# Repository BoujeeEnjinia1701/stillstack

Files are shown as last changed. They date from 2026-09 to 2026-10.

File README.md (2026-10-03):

# StillStack

     

**Area:** Water Security · **TRL:** 3 of 9 (proof of concept on paper) · **Value-engineering target:** USD 355 (estimated cost of the constructable design about USD 443) · **Difficulty:** 3 of 5

Multi-stage wick still that reuses the latent heat of condensation from each stage in the next one.

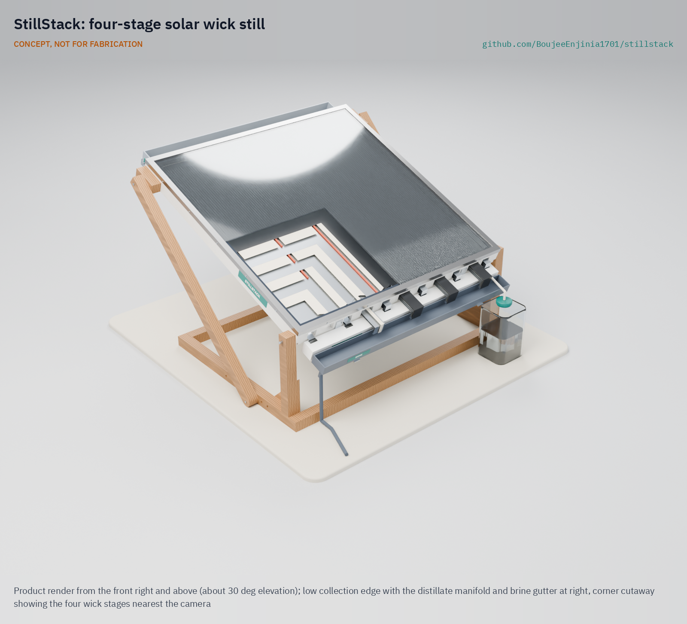
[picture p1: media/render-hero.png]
StillStack: four-stage solar wick still, product render


[Exploded render](media/render-exploded.png) · [Detail render](media/render-detail.png) · [Interactive 3D model](media/viewer.html) · [Concept blueprint (PDF)](media/concept-blueprint.pdf) · [General arrangement (PDF)](cad/drawings/SSK-DWG-002.pdf) · [Prototype build plan](docs/05-build-plan.md) · [Design decisions](docs/06-design-decisions.md) · [Sizing note](docs/04-calcs/01-sizing.md) · [Review note](docs/REVIEW.md)

## Concept rationale

A basin still wastes the heat it collects: vapor condenses on the glass and its latent heat goes to the sky. Stacking thin wick stages under metal plates lets each stage condense against the next one, so one day of sun evaporates water about four times over. The approach needs no pumps, electronics or membranes, which keeps it passive and repairable, and the calculated output of about 10.6 L per m2 per day is two to three times a basin still of the same area.

The design is open and garage-buildable because the people who need it most are rarely served by commercial desalination. Sheet aluminum, twin-wall polycarbonate, timber and cloth can be bought or salvaged almost anywhere, and a documented design lets an NGO, school or workshop build, test and adapt it rather than wait for a product.

## Burning platform

In 2024, 2.1 billion people, one in four worldwide, still lacked safely managed drinking water, and 106 million drank untreated surface water ([WHO and UNICEF, 2025](https://www.who.int/news/item/26-08-2025-1-in-4-people-globally-still-lack-access-to-safe-drinking-water---who--unicef)). The WHO estimates that in 2022 at least 1.7 billion people used a drinking water source contaminated with faeces, and that in 2021 over 2 billion people lived in water-stressed countries, a pressure that climate change and population growth are expected to worsen ([WHO drinking-water fact sheet](https://www.who.int/news-room/fact-sheets/detail/drinking-water)).

Many of these households sit beside seawater or above brackish aquifers that they cannot drink. Rising dry-season river salinity is projected across the southwest coast of Bangladesh by 2050 ([World Bank, 2015](https://www.worldbank.org/en/news/feature/2015/02/17/salinity-intrusion-in-changing-climate-scenario-will-hit-coastal-bangladesh-hard)). A still that turns salt water into distillate with sunlight alone, at several times the output of a basin still, addresses both problems at household scale.

## Where it could be used

### By industry

| Industry | Use |
| --- | --- |
| Humanitarian and WASH programs | Household or clinic distillate where only saline or brackish water is available |
| Island and remote tourism | Backup drinking and cooking water for eco-lodges and dive camps without reliable reverse osmosis |
| Off-grid energy | Distilled water for topping up lead-acid batteries in solar home and telecom systems |
| Education and technical training | A hands-on build for courses in heat transfer, water treatment and renewable energy |
| Field research stations | Low-salt water for rinsing instruments and small laboratory needs |

### By country or region

| Country or region | Why it matters there |
| --- | --- |
| Bangladesh (southwest coast) | Dry-season river salinity is projected to rise significantly by 2050, and eight coastal districts are the most affected ([World Bank](https://www.worldbank.org/en/news/feature/2015/02/17/salinity-intrusion-in-changing-climate-scenario-will-hit-coastal-bangladesh-hard)) |
| Kiribati (South Tarawa) | Groundwater from the freshwater lens can support only about half of South Tarawa's population, and households receive piped water for about 1.5 hours every two days ([World Bank](https://blogs.worldbank.org/en/eastasiapacific/drilling-for-water-in-kiribati)) |
| United States (Texas) | Texas aquifers hold about 2.7 billion acre-feet (about 3.3 x 10^12 m3) of brackish groundwater at 1,000 to 10,000 mg/L dissolved solids ([Texas Water Development Board](https://www.twdb.texas.gov/publications/reports/numbered_reports/doc/r363/b2.pdf)); small ranches and colonias could use it at household scale |
| Chile (Antofagasta region, Atacama coast) | The region holds the Atacama, the driest desert in the world, with about 1.7 mm of rain a year in Antofagasta; demand exceeds supply, and about 42 % of the rural population has no formal drinking-water supply ([Ruffino et al., IJERPH, 2022](https://doi.org/10.3390/ijerph192114406)) |
| Middle East and North Africa | The region has the world's lowest water availability per person, about 480 m3 a year in 2023, less than 10 % of the global average ([World Bank](https://blogs.worldbank.org/en/voices/in-mena-make-every-drop-of-water-count)); sun and seawater are plentiful |

## What sparked the idea

The starting point was a floating prototype that researchers at Politecnico di Torino tested in the Ligurian Sea at Varazze, Italy: a stack of thin evaporating and condensing layers fed by porous materials, with no pumps, which produced almost 3 L of distillate per m2 per hour from seawater at less than one sun ([Chiavazzo et al., Nature Sustainability, 2018](https://doi.org/10.1038/s41893-018-0186-x)); the university reported daily productivity of up to 20 L of drinking water per m2 ([Politecnico di Torino release via ScienceDaily](https://www.sciencedaily.com/releases/2019/01/190107131242.htm)). Their shift of attention from absorbing more sunlight to reusing the heat already absorbed is the principle behind StillStack. The gap it points at is that the result was a research device, not a design a community workshop could build; StillStack sets out to be that open, land-based, garage-buildable version.

## Problem

Single-basin solar stills make only about 3 to 5 L per m2 per day.

## Concept

Multi-stage wick still that reuses the latent heat of condensation from each stage in the next one.

The TRL 3 sizing (SSK-CAL-001) gives about 10.6 L per m2 per day on a 5.5 kWh per m2 day, with a gained output ratio of about 1.3. Dry stagnation reaches about 140 °C, so stages 1 and 2 use materials rated to 150 °C and a stagnation cover is supplied; the stage 3 margin is thin. Value-engineering target: USD 355. Estimated cost of the constructable design: USD 443.20 (USD 88.20 over the target).

Full design precis: [docs/02-concept.md](docs/02-concept.md)

## Key components

- Twin-wall polycarbonate glazing
- Insulated plywood frame with a stone wool liner
- Black aluminum absorber and four coated aluminum condenser plates
- Wick strips, four stages
- Side rails (150 °C polymer in stages 1 and 2, polycarbonate below) and silicone-cord spacer ribs
- Feed trough, lidded distillate manifold and brine gutter
- Rear heat-rejection fins and an adjustable tilt stand
- Opaque stagnation cover for when the feed runs out

The working bill of materials is in [bom/bom.csv](bom/bom.csv).

## Building the prototype

The [prototype build plan](docs/05-build-plan.md) (SSK-BLD-001) shows how to make each of the 20 components and put them together in 22 illustrated steps. The frame is a plywood box on a plywood base ring, lined with stone wool and closed by twin-wall glazing under an aluminium trim. The five aluminium plates are cut with a zigzag low edge so distillate leaves on tongues at the rib lines and brine on separate tongues over the closed manifold lid. The stand pivots on two front posts and is held by props pinned at one of six holes from 10° to 35°. The changes that made the concept buildable are in [SSK-DDR-003](docs/decisions/0003-design-for-construction.md), and decisions still open are in the [design decisions register](docs/06-design-decisions.md).

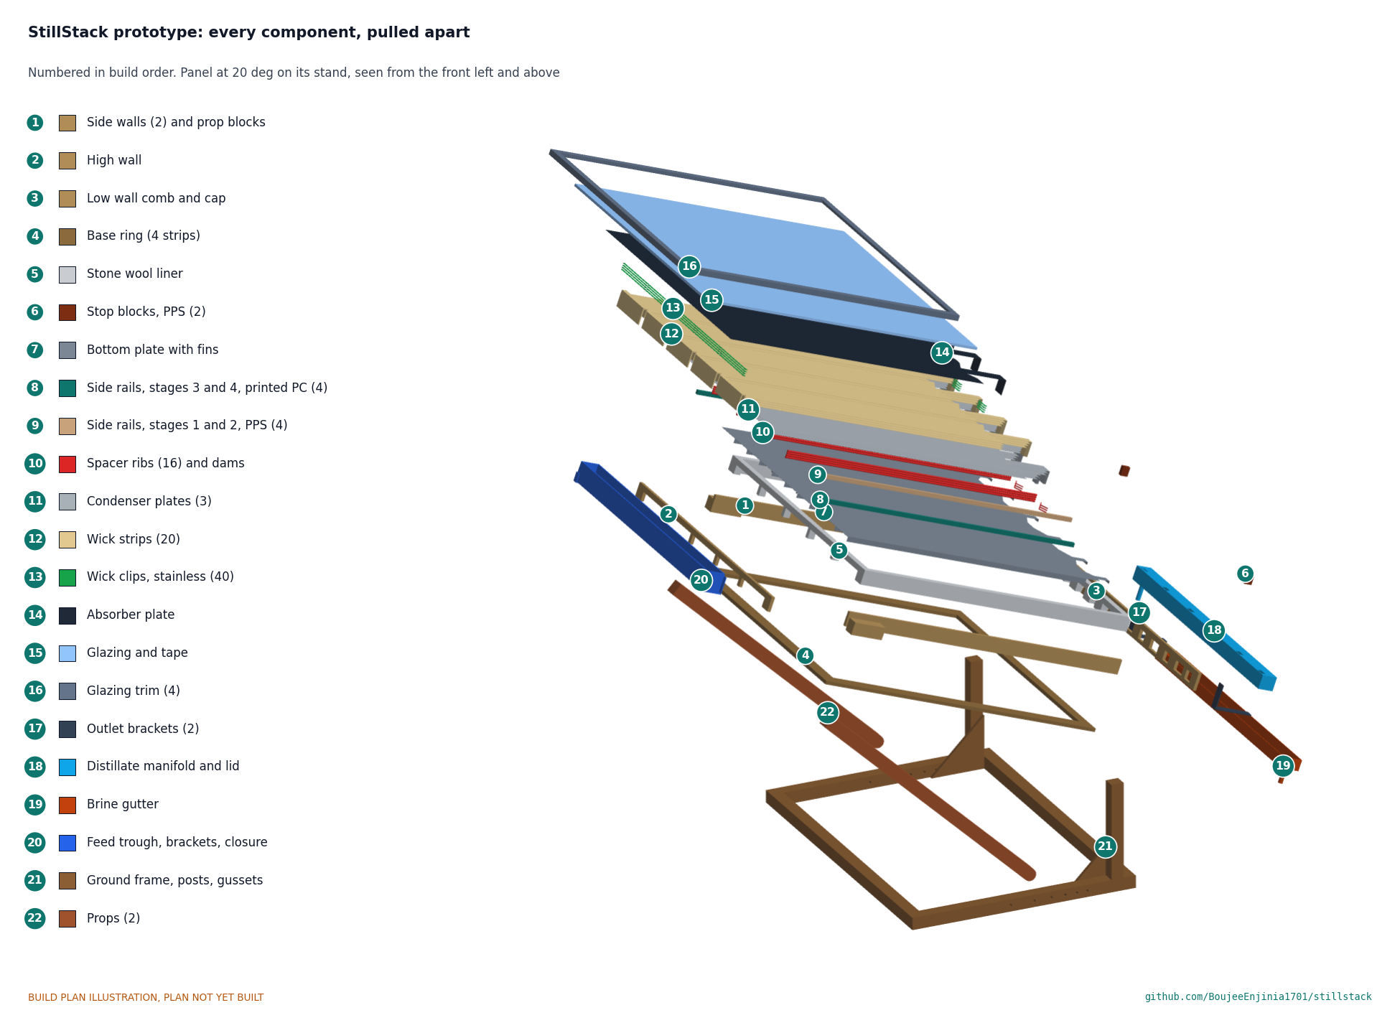
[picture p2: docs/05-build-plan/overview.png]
Every component of the StillStack prototype, pulled apart and numbered in build order


## Safety

> Distillate must be tested before drinking. Use food-safe materials on all wetted surfaces. The absorber reaches about 140 °C if the wicks run dry: fit the stagnation cover before maintenance and whenever the feed runs out. Anchor the stand against wind.

## Repository layout

| Folder | Contents |
| --- | --- |
| `docs/` | Problem, concept, requirements, calculations and design decisions |
| `cad/src/` | build123d Python source, the source of truth for all geometry |
| `cad/step/`, `cad/stl/` | Exported models for FreeCAD, other CAD tools and printing |
| `cad/drawings/` | 2D sketches and dimensioned drawings |
| `bom/` | Bill of materials |
| `electronics/` | KiCad schematics and PCB layouts |
| `firmware/` | Microcontroller code |
| `media/` | Renders, perspectives and photos |
| `build-log/` | Dated prototyping notes |

## Documentation

Controlled documents follow the portfolio [documentation standard](.kit/STANDARDS.md). Each carries a document ID (SSK-PRC-001 for the precis), a version and a revision history. Branded PDFs are built with `python .kit/render.py` and attached to GitHub Releases when a document is tagged, for example `SSK-PRC-001/v1.0`.

## Credits

Designed by Amish Chadha. See [CONTRIBUTORS.md](CONTRIBUTORS.md) for roles. To cite this design, use [CITATION.cff](CITATION.cff) (GitHub shows it as "Cite this repository").

AI assistance (Claude) was used to accelerate concept renders, prototype documentation and first-pass sizing calculations. Design direction and all decisions are Amish Chadha's, recorded in this repository's decision records (`docs/decisions/`).

## Licenses

- **Hardware** (CAD, drawings, BOM, electronics): [CERN-OHL-S v2](LICENSE)
- **Software** (firmware, scripts, notebooks): [MIT](LICENSE-SOFTWARE)

A project of the [Design Molecule](https://designmolecule.com) lab.

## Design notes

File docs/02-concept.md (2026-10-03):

---
doc_id: SSK-PRC-001
title: StillStack design precis
project: StillStack
doc_type: Design precis
version: "0.8"
status: Draft
date: '2026-10-02'
author: Amish Chadha
license: CERN-OHL-S-2.0
revisions:
- version: "0.1"
  date: '2026-09-24'
  author: Amish Chadha
  change: Initial scaffold
- version: "0.2"
  date: '2026-09-24'
  author: Amish Chadha
  change: Populate to TRL 2 (architecture, first-order numbers, design choices, safety, media)
- version: "0.3"
  date: '2026-09-25'
  author: Amish Chadha
  change: TRL 3 update; decided design choices (SSK-DDR-001), spacer ribs, numbers from SSK-CAL-001, parametric model and GA drawing
- version: "0.4"
  date: '2026-09-25'
  author: Amish Chadha
  change: Recommendations accepted by Amish (DDR-002)
- version: "0.5"
  date: '2026-09-26'
  author: Amish Chadha
  change: Budget top-up approved by Amish
- version: "0.6"
  date: '2026-10-01'
  author: Amish Chadha
  change: Constructable design (SSK-DDR-003, open for Amish's review); budget as a value-engineering target
- version: "0.7"
  date: '2026-10-02'
  author: Amish Chadha
  change: "Decisions of 2026-10-02: coating rule, wick fabric test and clips, PPS rails, high-edge lip, conductivity pass condition, partner, labels and rail colours"
- version: "0.8"
  date: '2026-10-02'
  author: Amish Chadha
  change: "Approved follow-ups carried into the design: mass 18.7 kg, cost USD 443.20, lip tabs and wick clips in the model"
---

# StillStack design precis

StillStack is a tilted, glazed panel of 1 m2 containing four thin evaporation stages stacked like a sandwich: each stage is a wet cloth wick under a metal plate, a 6 mm vapor gap, and the next plate below. Sunlight heats the top plate, and the heat released when vapor condenses on each plate evaporates water from the wick under it, so the same solar energy is used four times. The TRL 3 calculation (SSK-CAL-001) gives about 10.6 L of distillate per m2 per day on a 5.5 kWh per m2 day, roughly two to three times a single-basin still, with a gained output ratio of about 1.3. Dry stagnation reaches about 140 °C (144 °C in calm air), so stages 1 and 2 use materials rated to 150 °C and a stagnation cover is supplied (SSK-DDR-002). Value-engineering target: USD 355. Estimated cost of the constructable design: USD 416.20 (USD 61.20 over the target). How each part is made and fitted is in the prototype build plan (SSK-BLD-001); the changes that made the concept buildable are in SSK-DDR-003, open for Amish's review.

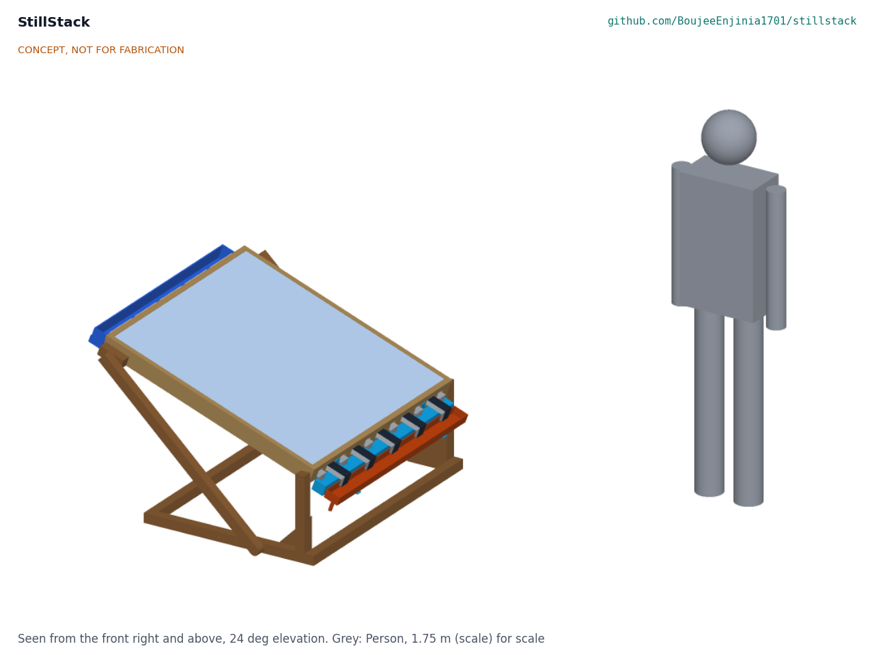
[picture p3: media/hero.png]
Hero render


## How it works

1. **Collect.** Sunlight passes through twin-wall polycarbonate glazing (solar transmittance about 0.80) and is absorbed by a black-coated aluminum plate. A 25 mm air gap under the glazing limits heat loss from the top.
2. **Evaporate, stage 1.** Cloth wick strips bonded to the underside of the absorber are kept wet with feed water. Heat conducts through the plate and evaporates water from the wick.
3. **Condense and reuse.** The vapor crosses a 6 mm gap and condenses on the top face of the next plate. The latent heat released there (about 2.35 MJ per kg at stage temperatures) conducts through that plate into the wick under it, which evaporates water into stage 2. The cascade repeats through four stages, each running about 3.7 K cooler than the one above at noon. Between 85 and 91 % of the heat crossing each gap at noon is latent.
4. **Hold the gaps.** Each gap has two side rails (a polymer rated to 150 °C in stages 1 and 2, printed polycarbonate in stages 3 and 4) and four silicone-cord ribs running down the slope at 194 mm pitch, so the 0.5 mm plates sag no more than about 0.5 mm. The wicks are cut into five strips with 10 mm dry breaks at every rib and rail.
5. **Reject heat.** The bottom plate is the last condenser. Folded aluminum fins on its shaded underside reject the remaining heat (6.6 MJ per day, peak 277 W/m2) to air at about 28 K above ambient.
6. **Feed and drain.** Feed water drips from a user-filled container into a trough along the high edge. The wick tails pass out through openings in the high wall, rise behind a foam closure and drop into the trough, and the wicks are fed by capillary action and gravity down the slope. Excess salty water leaves the low end of each wick into a brine gutter that sits outboard of, and lower than, the distillate manifold.
7. **Collect distillate.** Condensate runs down each condenser plate to its zigzag low edge, which leads it to six tongues at the rib lines and corners. The tongues pass through notches in the low wall and turn down through slots in a lidded distillate manifold, which drains through a spout into a clean covered container. Brine leaves on separate tongues at the strip centres, carrying the wick tails over the closed lid into the brine gutter (SSK-DDR-003, proposed, awaiting Amish).

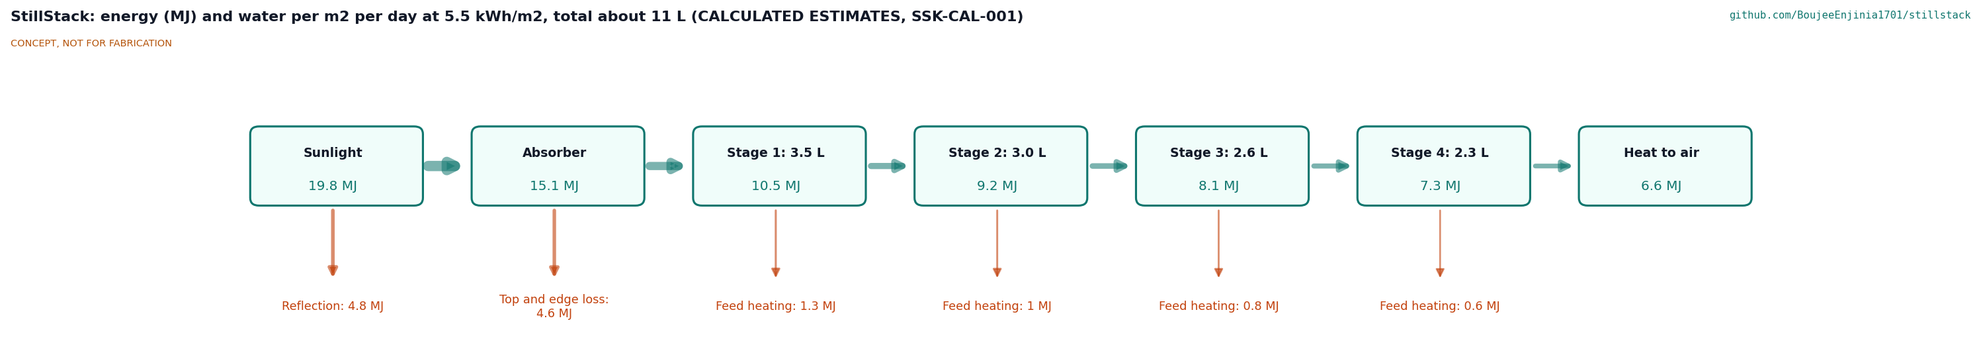
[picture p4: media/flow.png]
Energy and water flow (calculated estimates)


## Main components

Table 1. Main components, numbered to match the exploded view and bom/bom.csv.

| # | Component | Choice | Notes |
| --- | --- | --- | --- |
| 1 | Glazing | 6 mm twin-wall UV-stabilized polycarbonate, 1.0 x 1.0 m | Inner sheet reaches about 109 °C at dry stagnation |
| 2 | Insulated frame | 12 mm exterior plywood walls on a plywood base ring, with 25 mm foil-faced stone wool liner, 1,074 mm square outside; glazing held by an aluminium trim | Stone wool replaces PIR (SSK-DDR-002) because the absorber edge reaches about 144 °C at dry stagnation |
| 3 | Absorber plate | 0.5 mm aluminum, high-temperature matte black paint on top | Stage 1 evaporator surface underneath |
| 4 | Wicks, 4 stages | Viscose-polyester or cotton nonwoven, about 1 mm, 1.0 x 1.25 m, cut into five strips | Needs a permeability of 3.0 x 10^-11 m2 or more and must tolerate 150 °C dry; product not yet selected |
| 5 | Condenser plates, 4 | 0.5 mm aluminum with a food-contact coating on the condensing face; 77 mm lip into the manifold | Coating rated to 150 °C on plates 1 and 2 and certified for drinking-water contact; the lowest-cost such coating (fluoropolymer cookware coatings first), else 316 stainless plates 1 and 2 (decided 2026-10-02); 4 mm downturned lip on each condensing plate's high edge (decided 2026-10-02) |
| 6 | Side spacer rails | 12 x 7 mm, two per gap: stages 1 and 2 in PPS, rated to 150 °C or more (decided 2026-10-02); stages 3 and 4 in printed polycarbonate | Split by SSK-DDR-002; ASA excluded by the stagnation temperature |
| 7 | Spacer ribs | 7 mm food-grade silicone cord, four per gap at 194 mm pitch | Decided (SSK-DDR-002) |
| 8 | Feed trough | PVC or HDPE rain gutter section with end caps and drip valve | Fed from a user-filled container |
| 9 | Distillate manifold | Food-grade PP or HDPE channel with lid and silicone outlet tube | Separate outlet from the brine |
| 10 | Brine gutter | PVC gutter outboard of and below the distillate manifold, with drain hose | Brine to a soak-away or evaporation pond |
| 11 | Rear heat-rejection fins | Ten folded 0.5 mm aluminum strips, 30 mm deep | On the shaded underside of the bottom plate |
| 12 | Adjustable tilt stand | 45 x 45 mm timber ground frame, front posts with a pivot bolt, fixed props pinned at one of six holes | 10 to 35 deg in 5 deg steps (R11) |
| 13 | Sealant, fasteners and tubing | NSF/ANSI 51 or 61 silicone, stainless screws, silicone tube | Not shown in the model |
| 14 | Stagnation cover | Opaque white or aluminized tarpaulin 1.3 x 1.3 m with elastic edge cord | Fitted when the feed runs out and before maintenance; not shown in the model |

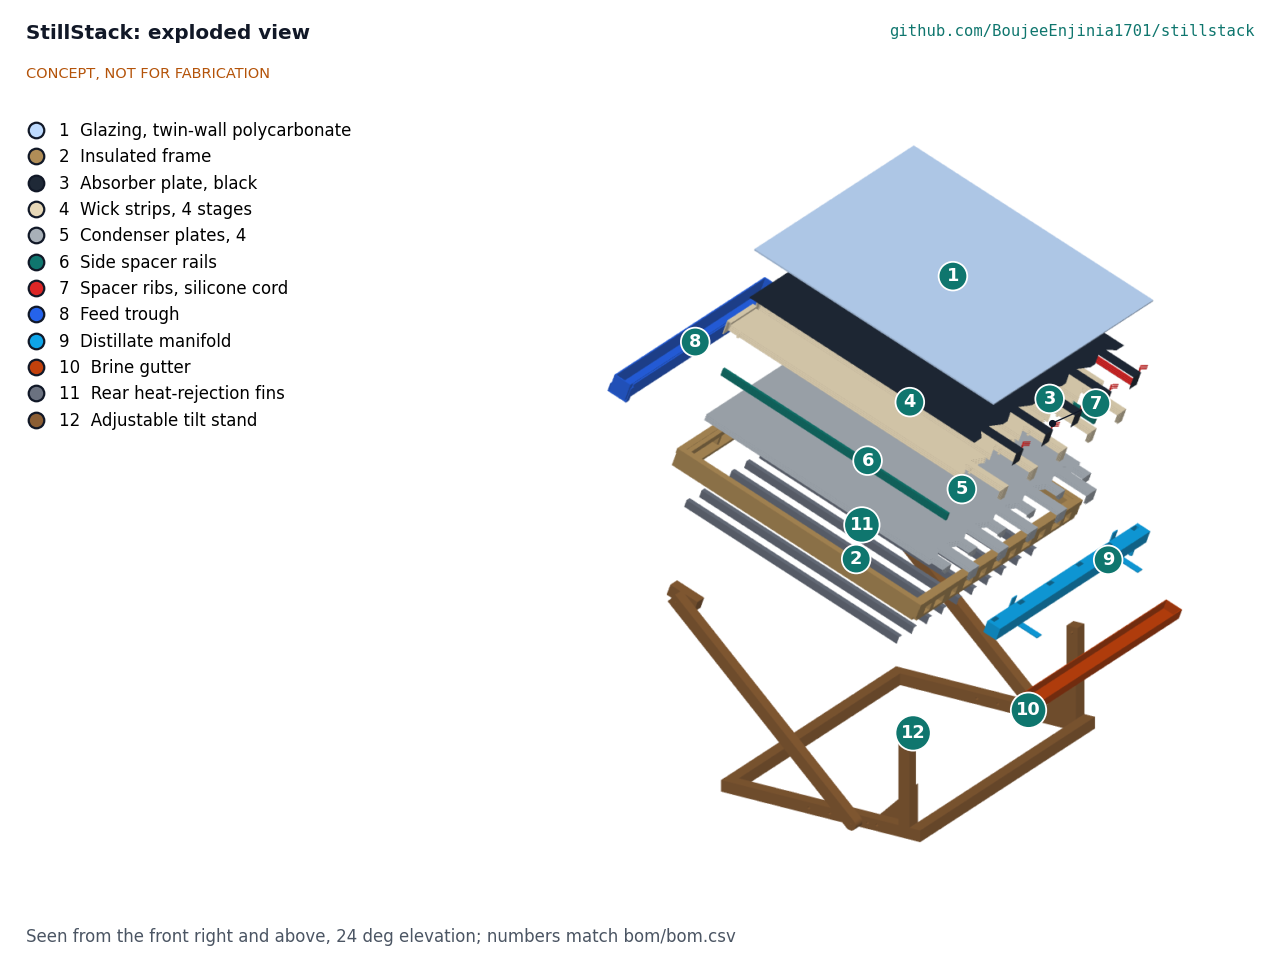
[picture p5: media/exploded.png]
Exploded view


## Key numbers

All values come from SSK-CAL-001 (quasi-steady stack model integrated over a 5.5 kWh per m2 design day) and are calculated estimates, not measurements.

Table 2. Key numbers per m2 of aperture.

| Quantity | Value | Requirement |
| --- | --- | --- |
| Solar input | 19.8 MJ per day | |
| Optical loss | 4.8 MJ (τα = 0.76) | |
| Top loss | 4.5 MJ | |
| Feed heating lost with brine | 3.8 MJ | |
| Heat rejected at the bottom | 6.6 MJ, peak 277 W/m2 | |
| Distillate by stage | 3.45, 2.97, 2.60, 2.29 L | |
| Daily distillate | 10.6 L after warm-up deduction (11.3 L quasi-steady); range 9.0 to 13.6 L for 4.5 to 6.5 kWh per m2 | R1 met, 6 % margin |
| Gained output ratio | 1.26 to 1.34 | R2 at risk |
| Plate temperatures at noon | 73, 69, 66, 62 and 58 °C | |
| Dry stagnation, stage 1 | about 140 °C (144 °C calm); stage 3 about 110 °C calm | R8 at risk (150 °C and 110 °C ratings) |
| Feed and brine | about 28.7 L feed, 17.2 L brine per day; brine 58 to 67 g/L | R6 at risk (wick feed) |
| Panel mass | 18.7 kg dry, 22.7 kg wet; stand 8.9 kg | R9 met |
| Parts cost | USD 443.20 against a USD 355 value-engineering target | R12 USD 88.20 over the target |

## Key design choices

These choices were decided by Amish on 2026-09-25 (SSK-DDR-001 and SSK-DDR-002).

- **Four stages with 6 mm gaps.** Decided. Three stages would give about 9.1 L per day; six stages about 14.9 L on paper.
- **Air-cooled fins under the bottom plate.** Decided. The bottom plate stays near 58 °C at noon, which is adequate for four stages.
- **Aluminum plates with a food-contact coating on the condensing face.** Decided. The coating product is not yet selected; see open questions.
- **Spacers in ASA or polycarbonate, not PETG.** Decided. SSK-CAL-001 shows that only polycarbonate is close to adequate, because stages 1 to 3 exceed the rating of ASA at dry stagnation.
- **Tilt of 20 deg on an adjustable stand.** Decided. The stand pivots at the low edge and sets the tilt with rear struts from 10 to 35 deg.
- **Aperture of 1 m2 and a value-engineering target of USD 355.** Decided. The budget was kept at $250 in SSK-DDR-001, raised to $320 in SSK-DDR-002 and topped up to $355 by Amish on 2026-09-26; on 2026-10-01 Amish set it as a value-engineering target, not a limit. The constructable design is estimated at USD 416.20.
- **Intermediate silicone-cord ribs.** Decided (SSK-DDR-002). The calculation shows that side rails alone cannot hold a 6 mm gap; silicone is rated well above the stagnation temperature and wets poorly.
- **Dry stagnation handled by materials and a cover.** Decided (SSK-DDR-002). Everything in stages 1 and 2 is rated to 150 °C or more, the frame liner is stone wool, and an opaque stagnation cover is supplied with a shade rule.

## Safety

> **Safety:** Distillate is not certified drinking water. Test it before drinking (at least conductivity and E. coli), store it in a clean covered container, and disinfect it (for example with chlorine) before use. Each stage's distillate conductivity test is a pass condition at TRL 4 before any water is drunk (decided 2026-10-02). Stages run below pasteurization certainty, brine can wick or splash into distillate channels, and volatile contaminants in the feed can carry over with the vapor. Long-term drinking of distillate needs remineralization.

> **Safety:** Use only food-contact rated materials on every surface that touches distillate: coated or stainless plates, PP or HDPE channels, and NSF/ANSI 51 or 61 silicone. Never use lead-containing solder, treated timber or recycled containers of unknown history in the water path.

> **Safety:** The absorber reaches about 80 °C in normal use and about 140 °C when the wicks run dry. Do not touch the glazing or open the stack in sun. Fit the stagnation cover (BOM line 14) before maintenance and whenever the feed container runs empty, and never leave a dry panel uncovered in sun.

> **Safety:** The panel and stand can overturn at about 17 m/s of wind. Anchor or ballast the stand.

- Brine is strongly saline. Discharge it away from crops, wells and soil that must stay fresh.

## Open questions

Decided by Amish on 2026-10-02 (SSK-DEC-001); the questions that remain are what the tests will show:

- Coating (R7): the lowest-cost coating certified for drinking-water contact (NSF/ANSI 61 or an equivalent food-contact statement) in hot salty water and rated to 150 °C dry; fluoropolymer (PTFE type) cookware coatings are checked first; if none meets both, 316 stainless for plates 1 and 2. Which product passes is still to be found.
- Wick fabric (R6): one polyester or polyester-viscose nonwoven and one glass-fibre fabric are shortlisted from datasheets and compared by a wicking-rise test; the cheaper one that reaches 3.0 x 10^-11 m2 and tolerates 150 °C dry is chosen. Wick fixing (R10): clips at the high and low ends, no adhesive.
- Rail polymer (R8): PPS for the stage 1 and 2 rails and stop blocks. Whether stage 3 can keep any margin over 110 °C in calm air is still open.
- Brine and feed separation (R4): the zigzag edge detail of SSK-DDR-003 (A1) and a 4 mm downturned lip on each condensing plate's high edge (A2); each stage's distillate conductivity at TRL 4 decides whether they work.
- Partner: a university water or desalination lab first; first candidate to approach, the Politecnico di Torino group behind the 2018 floating multistage still; a coastal NGO for field use once the distillate passes its tests. Nothing is agreed yet.
- Outlets and rails are marked DISTILLATE and BRINE, and the stage 1 and 2 rails have their own colour, so outlets are not mixed and a low-temperature rail is not fitted in a hot stage.

Design data: [general arrangement SSK-DWG-002](../cad/drawings/SSK-DWG-002.pdf), [sizing SSK-CAL-001](04-calcs/01-sizing.md), [parametric model](../cad/src/model.py), [blueprint sheet](../media/concept-blueprint.pdf), [interactive 3D model](../media/viewer.html), [cutaway](../media/cutaway.png).

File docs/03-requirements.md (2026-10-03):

---
doc_id: SSK-REQ-001
title: StillStack requirements
project: StillStack
doc_type: Requirements
version: "0.8"
status: Draft
date: '2026-10-02'
author: Amish Chadha
license: CERN-OHL-S-2.0
revisions:
- version: "0.1"
  date: '2026-09-24'
  author: Amish Chadha
  change: Initial scaffold
- version: "0.2"
  date: '2026-09-24'
  author: Amish Chadha
  change: First measurable requirements for TRL 2
- version: "0.3"
  date: '2026-09-25'
  author: Amish Chadha
  change: Add TRL 3 status from SSK-CAL-001; record decisions from SSK-DDR-001 (budget kept at $250, tilt stand, aperture); targets unchanged
- version: "0.4"
  date: '2026-09-25'
  author: Amish Chadha
  change: Recommendations accepted by Amish (DDR-002)
- version: "0.5"
  date: '2026-09-26'
  author: Amish Chadha
  change: Budget top-up approved by Amish
- version: "0.6"
  date: '2026-10-01'
  author: Amish Chadha
  change: Status from the constructable design (SSK-DDR-003); R12 reported against the value-engineering target
- version: "0.7"
  date: '2026-10-02'
  author: Amish Chadha
  change: "Decisions of 2026-10-02 noted under R4, R6, R7, R8 and R10 (lip, conductivity pass condition, fabric test, coating rule, PPS, wick clips); no status changed"
- version: "0.8"
  date: '2026-10-02'
  author: Amish Chadha
  change: "Approved follow-ups carried into the design: R9 mass 18.7 kg, R12 USD 443.20 (USD 88.20 over the target), R4 lip modelled, R10 moves from at risk to met on paper (wick clips modelled)"
---

# StillStack requirements

These requirements were checked by calculation at TRL 3 in SSK-CAL-001 v0.6. No requirement is **not met**; five are at risk and one cannot be verified until TRL 4. The TRL 2 review decisions (SSK-DDR-001) kept the 1 m2 aperture and the 20 deg tilt on an adjustable stand. Under SSK-DDR-002 (decided by Amish on 2026-09-25, going with the recommendations) R8 was restated with a 150 °C rating for stages 1 and 2 plus a stagnation cover, and the R12 budget was raised from $250 to $320. The added materials and cover bring the parts to $351.20. On 2026-09-26 Amish approved a budget top-up to $355 (SSK-DDR-002 v0.2). On 2026-10-01 Amish set every budget as a value-engineering target rather than a limit, so R12 is reported against it. The constructable design of SSK-DDR-003 (made under Amish's 2026-09-30 instruction to make the design buildable; open for his review) was estimated at USD 416.20. With the approved follow-ups of 2026-10-02 (PPS rails, wick clips, labels) it is estimated at USD 443.20, USD 88.20 over the USD 355 target. Carrying the wick clips into the model moves R10 from at risk to met on paper; no other status changes.

Table 1. Requirements and status at TRL 3.

| ID | Requirement | Target | Verification (TRL 3 or later) | Status at TRL 3 (SSK-CAL-001) |
| --- | --- | --- | --- | --- |
| R1 | Produce more distillate per unit area than a basin still | 10 L per m2 of aperture per day or more on a clear day with 5.5 kWh per m2 of sun (design goal 13 L) | Stage energy balance calculation; later outdoor test with a single-basin still alongside | Met on paper: 10.6 L after warm-up deduction (11.3 L quasi-steady); the 13 L goal is not met |
| R2 | Reuse the latent heat of condensation | Daily gained output ratio (latent heat in distillate divided by solar input) of 1.3 or more | Stage energy balance calculation | At risk: 1.34 quasi-steady, 1.26 after warm-up deduction |
| R3 | Remove salt | Distillate conductivity 75 µS/cm or less (about 50 mg/L dissolved solids) from feed up to 40 g/L salinity | Calculation of carryover paths; later conductivity meter | Not verifiable at TRL 3: brine carryover must stay below 0.075 % of the distillate (8.5 mL per day) |
| R4 | Keep brine and distillate apart | A physical air break of 10 mm or more between every wick edge and every distillate channel; no shared drain | Design review of the model | At risk: 10 mm dry breaks at ribs, rails and inside the plate edges; brine tongues carry the wick tails 10.5 mm or more above the closed manifold lid and at least 44 mm from any distillate tongue (SSK-DDR-003 A1, accepted 2026-10-02); feed tails cross the condensing plates' high edges 6 mm above them, to be guarded by a 4 mm downturned lip on each condensing plate's high edge (A2 (c), decided 2026-10-02, now in the model as four tabs on each plate). Each stage's distillate conductivity test at TRL 4 is a pass condition before any water is drunk |
| R5 | Run without power | No pumps, electronics or batteries; gravity feed from a user-filled container at most 1.5 m above ground | Design review | Met: fully passive; feed trough rim at most 1.00 m (at 35 deg) |
| R6 | Accept real feed water | Seawater or brackish water up to 40 g/L salinity after cloth or 20 µm prefiltering; feed-to-distillate ratio 2.5 or more so salt stays in solution | Salt balance calculation | At risk: brine at 66.7 g/L is well below saturation, but the wick needs a permeability of 3.0 x 10^-11 m2 or more to carry the feed, which is not yet known; the fabric is chosen by a wicking-rise test between a polyester-type nonwoven and a glass-fibre fabric (decided 2026-10-02) |
| R7 | Food-safe wetted parts | Every surface that touches distillate is food-contact rated (for example 316 stainless steel, food-grade coated aluminum, PP, HDPE or NSF/ANSI 51 or 61 silicone) | Material list review | At risk: coated aluminum is decided, the coating class is selected (fluoropolymer, PTFE or PFA type, BOM line 5) but no named product with a drinking-water certificate for wet, salty service at 80 °C (and 150 °C dry on plates 1 and 2) has been seen. Rule decided 2026-10-02: the lowest-cost coating certified for drinking-water contact and rated to 150 °C dry (fluoropolymer cookware coatings first), else 316 stainless for plates 1 and 2 |
| R8 | Survive dry stagnation | No damage after an empty-wick day at 1,000 W/m2 and 35 °C ambient, in calm air or wind: materials in stages 1 and 2 (absorber to plate 2, including wicks, rails, ribs, coating and liner) rated to 150 °C or more; all other internal materials rated to 110 °C or more; a stagnation cover supplied and a shade rule in the instructions (restated under SSK-DDR-002) | Stagnation temperature calculation; material datasheets | At risk: stages 1 and 2 reach 144 °C in calm air (6 K margin); stage 3 reaches 110 °C in calm air (0 K margin); cover specified (BOM line 14); rail polymer decided as PPS (2026-10-02, BOM line 6); coating class selected (fluoropolymer) but its drinking-water certificate not yet seen |
| R9 | Household scale and portable | 1.0 m2 aperture; panel mass 20 kg or less dry; carried by two people; footprint within 1.3 x 1.3 m | Massing model and mass estimate | Met: 18.7 kg dry (22.7 kg wet); footprint 1.28 x 1.25 m at 10 deg |
| R10 | Easy maintenance | Wicks removable, rinsed and refitted by one person without special tools in 30 min or less; salt flushing no more often than once a week | Design review | Met on paper: the plates lift out once the low wall cap is off, and each wick is held by two stainless clips, at its high end and on its brine tongue, with no adhesive (decided 2026-10-02; in the model, SSK-DWG-119 and 120), so the wicks lift out; the 30 minute time is to be shown at TRL 4 |
| R11 | Adjustable tilt | Tilt between 10 and 35 deg to suit latitudes of about 0 to 35 deg | Model check | Met: props pinned at six holes, 10 to 35 deg in 5 deg steps; model built and checked at each |
| R12 | Low cost and buildable | Parts cost against a value-engineering target of USD 355 for the 1 m2 prototype (budget_usd; a hypothetical control target, not a limit, Amish 2026-10-01); hand tools, sheet metal shears and a 3D printer only | Priced BOM | USD 88.20 over the value-engineering target: estimated USD 443.20 for the constructable design (SSK-DDR-003, with the PPS rails, wick clips and labels of 2026-10-02) |

## Assumptions

- Design day: 5.5 kWh per m2 per day (19.8 MJ per m2) on the tilted aperture, 30 °C mean daytime ambient, light wind (1 m/s in SSK-CAL-001).
- Latent heat of vaporization: SSK-CAL-001 uses temperature-dependent values (about 2.33 to 2.36 MJ per kg over the stage range) in place of the flat 2.26 MJ per kg used at TRL 2.
- The WHO does not set a health-based limit for dissolved solids; 50 mg/L is chosen as a check that salt carryover is negligible, not as a potability limit.
- Household need of about 3 L per person per day for drinking and 2 L for cooking, so 10 to 11 L per day serves a household of two.

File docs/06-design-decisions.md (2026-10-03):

---
doc_id: SSK-DEC-001
title: StillStack design decisions register
project: StillStack
doc_type: Design decisions register
version: "0.3"
status: Draft
date: '2026-10-02'
author: Amish Chadha
license: CERN-OHL-S-2.0
revisions:
  - version: "0.1"
    date: '2026-10-01'
    author: Amish Chadha
    change: Register opened with the design for construction (SSK-DDR-003); budget treated as a value-engineering target
  - version: "0.2"
    date: '2026-10-02'
    author: Amish Chadha
    change: "Amish approved the recommendations for open decisions 1 to 9 (2026-10-02); moved to decisions made (SSK-DDR-003 accepted, A2 as option (c))"
  - version: "0.3"
    date: '2026-10-02'
    author: Amish Chadha
    change: "Value engineering restated for the follow-ups carried into the design (USD 443.20, USD 88.20 over the target); two items to confirm when parts are bought"
---

# StillStack design decisions register

Every design decision still to be made, and every decision made, in one place. Each decision is argued in full in its decision record under `docs/decisions/`; this register is the index Amish works from. The build plan (`docs/05-build-plan.md`) describes the design as it stands and does not list open decisions.

## Open decisions

None. All open decisions were decided on 2026-10-02.

## To confirm when parts are bought

| # | What to confirm | Why it matters | Source |
| --- | --- | --- | --- |
| 1 | The manifold channel is about 56 x 50 mm with a snap-on lid that can be slotted | Sets the tongue bends and the lid slots (sketch SSK-DWG-114) | SSK-DDR-003 |
| 2 | The brine gutter is about 70 x 40 mm and the trough about 70 x 70 mm, with fascia brackets that fit it | Sets the outlet bracket length and the trough position | SSK-DDR-003 |
| 3 | The stone wool board has a compressive strength of 10 kPa or more | The glazing edge and its trim press on the liner tops | SSK-DDR-003 |
| 4 | The twin-wall sheet can be cut to 1,060 mm square with the flutes running down the slope, and breather tape is available for the flute ends | Drainage of condensate and rain from the flutes | SSK-PRC-001 |
| 5 | 7 mm PPS sheet (the stage 1 and 2 rail polymer, decided 2026-10-02) is sold in strips or small sheets | The rails and stop blocks are cut from it | SSK-DDR-002 |
| 6 | The coating and the high-temperature silicone adhesive bond to each other and to bare aluminium | The fins are bonded under the bottom plate; the chevron dams sit on the coating | SSK-DDR-003 |
| 7 | A quote for the 7 mm PPS sheet (BOM line 6 is priced at a distributor list price of about USD 70 per kg, not a quote) | The rails cost about USD 46 for four at that price | SSK-DEC-001 |
| 8 | The coater supplies an NSF/ANSI 61 or equivalent drinking-water certificate for the fluoropolymer coating in hot salty water, rated to 150 °C dry | Decides whether plates 1 and 2 keep the coating or move to 316 stainless | SSK-DEC-001 |

## Value engineering

Value-engineering target: USD 355 (a hypothetical control target, not a limit). Estimated cost of the constructable design: USD 443.20 (USD 88.20 over the target). Main cost drivers and savings worth trying:

- The largest lines are the five coated aluminium plates (USD 128 together, lines 3 and 5), the side rails (USD 60, line 6), the frame and liner (USD 35), the glazing (USD 32), the stand (USD 28) the glazing trim and tape (USD 20) and the 40 stainless wick clips (USD 14).
- The decisions of 2026-10-02 added USD 27: PPS rails at list price (USD 10), the wick clips (USD 14) and the labels (USD 3).
- Making the design constructable added USD 65: larger plate blanks for the tongues (USD 20), the glazing trim and tape (USD 20), the stand's ground frame, gussets and pins (USD 7), brackets for the trough and outlets (USD 10), the feed closure (USD 6) and longer wicks (USD 2).
- Savings worth trying: nest the plates' tongues when ordering cut sheet so the blank is nearer 1.0 x 1.1 m (about USD 10); fold the trim from aluminium flashing instead of buying angle (about USD 8); silicone strip in place of the 150 °C polymer rails in stages 1 and 2 (about USD 14, from SSK-DDR-002) is not a saving to take, because it would undo the R8 materials decision (SSK-DDR-002, item 2) and the PPS rails decided on 2026-10-02; move the brine gutter closer to the manifold to shorten the brine tongues; reclaimed timber for the stand; a locally made stagnation cover.

## Decisions made

| Date | Decision | Decided by | Record |
| --- | --- | --- | --- |
| 2026-09-25 | Four stages with 6 mm gaps; air-cooled fins; aluminium condenser plates with a food-contact coating; spacers in ASA or polycarbonate, not PETG; 20 deg tilt on an adjustable stand; 1 m2 aperture; budget kept at USD 250 | Amish: "proceed with all of your recommendations across all batches. Make sure we don't proceed to TRL 4 on any of them." | [SSK-DDR-001](decisions/0001-trl2-review-decisions.md) |
| 2026-09-25 | Silicone-cord ribs; R8 response (c): 150 °C materials in stages 1 and 2, stone wool liner, stagnation cover; budget raised to USD 320 | Amish: "i accept all your recommendations, go with them across all repos." | [SSK-DDR-002](decisions/0002-recommendations-accepted.md) |
| 2026-09-26 | Budget top-up to USD 355 | Amish: "I am ok with the budget top ups" | [SSK-DDR-002](decisions/0002-recommendations-accepted.md) v0.2 |
| 2026-09-30 | Make the design physically buildable while drawing the build plan | Amish: "If you are realising that the design cannot be built as per concept - fix the design assumptions to match and be physically feasible as you draw the illustrations." | [SSK-DDR-003](decisions/0003-design-for-construction.md) (changes accepted on 2026-10-02, below) |
| 2026-09-30 | Open decisions live in this register, not in the build plan | Amish: "don't log outstanding decisions in this build plan - that is not the place for it." | This register |
| 2026-10-01 | `budget_usd` is a value-engineering target, not a limit | Amish: "the budgets are a hypothethical control target to ensure we are thinking along a value engineering lens" | This register, Value engineering |
| 2026-10-02 | Design for construction accepted: the changes P1 to P12 and their knock-on changes, as made, with the two brine-separation details decided separately (A1 and A2, below) and the wick fixing of P11 replaced by the clip decision below | Amish: "i approve your recommendations for all 555 open decisions." | SSK-DDR-003, Table 1 |
| 2026-10-02 | Brine exit (R4, safety case): option (a), the zigzag edges with separate distillate and brine tongues; each stage's distillate conductivity test is a pass condition at TRL 4 before any water is drunk; the cross-wick (b) is the fallback | Amish: "i approve your recommendations for all 555 open decisions." | SSK-DDR-003, A1 |
| 2026-10-02 | Feed tails at the high edge (R4, safety case): option (c) now (changed from the register's (a)). A 4 mm downturned lip on each condensing plate's high edge, bent before coating; dropped only if TRL 4 conductivity tests without it show no carryover | Amish: "i approve your recommendations for all 555 open decisions." | SSK-DDR-003, A2 |
| 2026-10-02 | Wick fixing (R10): clips at each wick's high and low ends (stainless, or the 150 °C rail polymer in stages 1 and 2) and no adhesive, so the wicks lift out once the plates are up | Amish: "i approve your recommendations for all 555 open decisions." | SSK-PRC-001, open questions |
| 2026-10-02 | Coating (R7): the lowest-cost coating certified for drinking-water contact (NSF/ANSI 61 or an equivalent food-contact statement) in hot salty water and rated to 150 °C dry; first class to check, fluoropolymer (PTFE type) cookware coatings. If none meets both, 316 stainless for plates 1 and 2 | Amish: "i approve your recommendations for all 555 open decisions." | SSK-DDR-002, item 5 |
| 2026-10-02 | Wick fabric (R6): shortlist from datasheets one polyester or polyester-viscose nonwoven and one glass-fibre fabric, run a wicking-rise test on each, and pick the cheaper one that reaches 3.0 x 10^-11 m2 and tolerates 150 °C dry | Amish: "i approve your recommendations for all 555 open decisions." | SSK-DDR-002, item 5 |
| 2026-10-02 | Rail polymer (R8): PPS for the stage 1 and 2 rails and stop blocks | Amish: "i approve your recommendations for all 555 open decisions." | SSK-PRC-001, open questions |
| 2026-10-02 | First co-design partner: a university water or desalination lab first; first candidate to approach, the Politecnico di Torino group behind the 2018 floating multistage still. A coastal NGO for field use once the distillate passes its tests | Amish: "i approve your recommendations for all 555 open decisions." | SSK-DDR-001, item 8 |
| 2026-10-02 | Appearance items adopted, all five: glazing flutes down the slope, removable manifold lid, drip valve at the front end, DISTILLATE and BRINE labels, and different rail colours for stages 1 and 2 | Amish: "i approve your recommendations for all 555 open decisions." | docs/REVIEW.md, 2026-09-26 |

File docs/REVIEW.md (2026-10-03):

# Review note: StillStack

## Session 2026-09-24: /populate to a strong TRL 2

### What was done

- `docs/01-problem.md` (SSK-PRB-001 v0.2): the problem, users and context (arid and saline coastal households, clinics and schools, remote outposts, makerspaces), constraints, out of scope, prior research described without links.
- `docs/03-requirements.md` (SSK-REQ-001 v0.2): 12 measurable requirements (R1 to R12) with targets, planned verification and stated assumptions.
- `docs/02-concept.md` (SSK-PRC-001 v0.2): how it works, main components numbered to match the exploded view and BOM, first-order energy balance, design choices, safety, open questions.
- `cad/src/concept_media.py`: massing model of a 1 m2 tilted panel (glazing, insulated frame, absorber, four wicks, four condenser plates, spacers, feed trough, distillate manifold, brine gutter, fins, tilt stand) with the 1.75 m figure for scale.
- `media/`: hero, blueprint sheet SSK-DWG-001 (PNG and PDF), cutaway, exploded view with BOM callouts, energy and water flow diagram marked as estimates, `model.glb` and `viewer.html`.
- `bom/bom.csv`: 12 lines with indicative prices, numbered to match the exploded view; `bom/bom-notes.md`.
- `README.md`: hero image and links line.
- `docs/pdf/`: branded PDFs of the three controlled documents.

### Key results (estimates, to be checked at TRL 3)

| Quantity | Estimate | Requirement |
| --- | --- | --- |
| Solar input | 19.8 MJ per m2 per day (5.5 kWh) | |
| Single-stage yield | about 3.8 L per m2 per day | Matches basin stills |
| Four-stage yield | about 13.2 L per m2 per day (range 10.5 to 17.5) | R1 met on paper |
| Gained output ratio | about 1.5 | R2 met on paper |
| Stage 1 temperature | about 70 to 80 °C at noon | |
| Heat to reject at the bottom | about 8.1 MJ per day, peak about 280 W/m2 | |
| Panel mass | about 15 kg dry | R9 met |
| Parts cost | about $241 | R12 met, about $9 margin |

Requirements not met or at risk:

- **R7 (food-safe wetted parts):** not met by bare aluminum condenser plates. It depends on a coating or stainless choice that is still open.
- **R8 (dry stagnation):** not met by the PETG "printed spacers" in the original scaffold. The precis and BOM now specify ASA or polycarbonate, pending approval.
- **R11 (adjustable tilt):** not met by the massing model, which has a fixed 20 deg stand.
- **R12 (cost):** met with almost no margin. The stainless plate option would exceed the $250 budget.
- **R1 and R2:** depend on an assumed evaporation fraction of 0.70 per stage and on air fins rejecting about 280 W/m2. Both are unverified and are the main technical risks.

### Proposed, awaiting Amish (items 1 to 7 since decided, see SSK-DDR-001)

1. Four stages with 6 mm gaps. Alternatives: three stages (simpler, about 10.5 L) or six stages (only with a water-cooled bottom). Decided by Amish, 2026-09-25: go with recommendation.
2. Air-cooled fins under the bottom plate. Alternatives: a feed-water tray heat sink, or floating the unit on water. Decided by Amish, 2026-09-25: go with recommendation.
3. Condenser plates in aluminum with a food-grade coating (recommended on cost). Alternatives: 316 stainless steel (over budget by about $100 to $150) or anodized aluminum. Decided by Amish, 2026-09-25: go with recommendation.
4. Spacers in ASA or polycarbonate instead of PETG. Decided by Amish, 2026-09-25: go with recommendation.
5. Tilt of 20 deg, with an adjustable stand to meet R11. Decided by Amish, 2026-09-25: go with recommendation.
6. Prototype aperture of 1 m2 (alternative: 0.5 m2 to add budget margin). Decided by Amish, 2026-09-25: go with recommendation.
7. Keep the budget at $250. No budget change is proposed now, but the stainless option would need one. Decided by Amish, 2026-09-25: go with recommendation.
8. First co-design partner: a coastal NGO, a university water lab or a makerspace network. No recommendation; still proposed, awaiting Amish.

### Safety concerns

- Distillate is not certified drinking water. The documents require testing (conductivity, E. coli), clean covered storage and disinfection, and they note brine carryover, volatile carryover and the need for remineralization.
- All wetted surfaces on the distillate side must be food-contact rated. Bare aluminum and unknown plastics are excluded.
- Hot surfaces: about 70 to 80 °C in use and above 100 °C when dry. Shade the panel before maintenance.
- A 1 m2 tilted panel can tip over in wind, so the stand must be anchored. Brine must be discharged away from crops and wells.

### Recommended next step

Review this note and the media. If approved, run `/advance-trl3` to write the stage energy balance calculation (gap heat transfer, evaporation fraction, heat rejection and stagnation temperature), select the condenser coating and wick, and produce the parametric model and drawing sheet.

## Session 2026-09-25: TRL 3

### What was done

Amish accepted every TRL 2 recommendation on 2026-09-25 and instructed that no repo proceeds to TRL 4. This session advanced StillStack to TRL 3 (trl: 3, trl_target: 3).

- `docs/decisions/0001-trl2-review-decisions.md` (SSK-DDR-001 v0.1): seven decisions recorded; the co-design partner stays open.
- `docs/04-calcs/01-sizing.md` (SSK-CAL-001 v0.1) and `docs/04-calcs/sizing.py`: quasi-steady stage energy balance over a design day (Stefan diffusion, conduction and radiation across each gap; top-loss network; fin and radiation heat rejection; feed sensible heat; warm-up deduction), plate sag and rib pitch, dry stagnation, wick feed capacity, salt balance and carryover allowance, mass, tilt and footprint, wind overturning and BOM cost. The script prints every number the note quotes.
- `cad/src/model.py`: parametric build123d model (tilt, aperture, stage count, gap, rib count, wall build-up and stand as parameters) exporting `cad/step/stillstack-assembly.step`, `cad/stl/stillstack-assembly.stl` and `cad/stl/side-rail.stl`; it prints part masses and checks the tilt range at 10, 20 and 35 deg.
- `cad/src/sheets.py` and `cad/drawings/SSK-DWG-002.svg`, `.pdf`, `.png`: general arrangement at Rev P1, "PRELIMINARY, NOT FOR FABRICATION", with three views at 1:20, isometric view, stack detail at 2:1 and low-edge detail at 1:2. The concept blueprint remains SSK-DWG-001 (now Rev P2).
- `bom/bom.csv` (13 lines, every line priced with a supplier type) and `bom/bom-notes.md`.
- `cad/src/concept_media.py` now builds from the parametric model; all media in `media/` refreshed and inspected (hero, blueprint, cutaway, exploded view with BOM callouts 1 to 12, flow diagram with calculated values, `model.glb`, `viewer.html`). The scale figure was moved clear of the panel so it no longer overlaps the isometric view.
- `docs/01-problem.md`, `docs/02-concept.md` and `docs/03-requirements.md` at v0.3; `project.yaml` and `README.md` updated; PDFs rebuilt in `docs/pdf/`.

### Requirements at TRL 3 (not met first)

| ID | Status | Key figure |
| --- | --- | --- |
| R8 | **Not met** | Dry stagnation about 140 °C at stage 1 (144 °C in calm air), above the 110 °C rating |
| R12 | **Not met** | Parts $317.20 against $250 ($67.20 over) |
| R2 | At risk | Gained output ratio 1.34 quasi-steady, 1.26 after warm-up deduction (target 1.3) |
| R4 | At risk | 10 mm breaks modeled at ribs and rails; brine exit over the lidded manifold not detailed |
| R6 | At risk | Brine 66.7 g/L is fine; wick needs a permeability of 3.0 x 10^-11 m2 or more, unknown |
| R7 | At risk | Coating product for wet, salty service at 80 °C not selected |
| R10 | At risk | Bonded wicks; removal method not defined |
| R3 | Not verifiable at TRL 3 | Brine carryover must stay below 0.075 % (8.6 mL per day) |
| R1 | Met | 10.6 L per m2 per day (11.3 quasi-steady); the 13 L goal is not met |
| R5 | Met | Passive; feed trough top at most 1.06 m |
| R9 | Met | 15.9 kg dry, 19.9 kg wet; footprint 1.28 x 1.16 m |
| R11 | Met | Stand and model at 10 to 35 deg |

Numbers the TRL 2 documents overstated and that are now corrected: 13.2 L per day (now 10.6 to 11.3 L), gained output ratio 1.5 (now 1.26 to 1.34), glazing transmittance 0.88 (now 0.80 for twin-wall polycarbonate), stagnation 100 to 120 °C (now about 140 °C), feed 35 L and brine 22 L (now 28.7 and 17.2 L), cost $241 (now $317.20). The TRL 2 assumption of an evaporation fraction of 0.70 was conservative; the calculation gives 0.85 to 0.91 at noon. The main new losses are the sensible heat of the feed (3.8 MJ per day) and the lower glazing transmittance.

A structural finding changed the model: 0.5 mm plates held only by side rails would sag about 325 mm, so four intermediate ribs per gap at 194 mm pitch were added (sag 0.52 mm), with the wicks cut into strips around them.

### Decisions recorded (SSK-DDR-001)

Decided by Amish, 2026-09-25, going with the recommendation: four stages with 6 mm gaps; air-cooled fins; aluminum condenser plates with a food-contact coating; spacers in ASA or polycarbonate, not PETG; 20 deg tilt on an adjustable stand; 1 m2 aperture; budget kept at $250 with no redefinition.

### Still awaiting Amish

1. First co-design partner (coastal NGO, university water lab or makerspace network). No recommendation made.
2. **Intermediate spacer ribs** (new): silicone cord (recommended: rated well above 140 °C and poorly wetting, so it limits brine creep) or printed polycarbonate. About $20 either way. Decided by Amish, 2026-09-25: go with recommendation. Silicone cord (SSK-DDR-002).
3. **Response to R8 not met** (new). Options: (a) specify materials rated to about 150 °C in stages 1 and 2 (silicone ribs, high-heat polycarbonate or PPS rails, higher-rated liner) and change the R8 rating to match the calculated stagnation temperature; (b) keep R8 as written and add a stagnation cover or a shade rule when the feed runs out; (c) both. Recommendation: (c), since a cover also protects the glazing. Decided by Amish, 2026-09-25: go with recommendation. Option (c) (SSK-DDR-002).
4. **Response to R12 not met** (new). Options: (a) raise budget_usd to about $320; (b) keep $250 and cut cost (for example ribs and rails from one material, a cheaper frame liner, or fewer coated faces); (c) redefine the budget to exclude the stand. Recommendation: (a), because the extra cost comes from parts the calculation shows are needed. The budget is not changed here. Decided by Amish, 2026-09-25: go with recommendation. Option (a), budget_usd $320 (SSK-DDR-002).
5. Coating product for the condensing faces (R7) and wick fabric with a permeability of at least 3.0 x 10^-11 m2 (R6). Both are selections that need datasheets; no product is recommended yet. Still proposed, awaiting Amish.

### Safety concerns

- Dry stagnation reaches about 140 °C at the absorber and about 109 °C at the inner glazing sheet. This is a burn hazard and can damage the stack if the feed runs out in sun.
- Lift on the panel equals its weight at about 17 m/s of wind; the stand must be anchored or ballasted.
- Distillate is not certified drinking water. Brine carryover of more than about 8.6 mL per day would exceed the 50 mg/L check, so test before drinking and disinfect.
- Brine (up to about 67 g/L) must be discharged away from crops and wells.

### Other notes

- No TRL 4 material (tests, build procedures, purchasing lists, build-log entries) exists in the repo, and none was created. STANDARDS section 9 asks for TRL changes to be recorded in the build log; no build-log entry was added, because build-log material is outside this session's scope. The change is recorded here and in `project.yaml`.
- No citations were flagged as unchecked in the TRL 2 review, so no web verification was attempted. The two research papers named in SSK-PRB-001 remain described without links.
- Material limits quoted for ASA, polycarbonate, PIR and twin-wall sheet are typical values, not datasheet checks.

### Recommended next step

TRL 4 is on hold by Amish's instruction. The recommended next step is for Amish to decide items 2 to 4 above, after which SSK-CAL-001 and the BOM can be rerun on paper. For reference only, TRL 4 would need: a lab test article of one or two stages, a test report (TST, environment: lab) measuring gap heat transfer, evaporation fraction, wick feed rate and distillate conductivity, and build-log entries. None of that should start until Amish lifts the TRL 3 cap.

## Session 2026-09-25: recommendations accepted

### Decisions applied

Amish wrote on 2026-09-25: "i accept all your recommendations, go with them across all repos." Three items that carried a recommendation are now decided and recorded in `docs/decisions/0002-recommendations-accepted.md` (SSK-DDR-002 v0.1):

1. **Intermediate spacer ribs:** silicone cord, as recommended. Already in the model and BOM; now a decided choice (no cost or geometry change).
2. **Response to R8 not met:** option (c), both. Materials in stages 1 and 2 rated to 150 °C (four side rails in PPS or a high-heat polycarbonate copolymer; frame liner changed from PIR to foil-faced stone wool; wick and plate 1 and 2 coating to tolerate 150 °C), R8 restated (150 °C in stages 1 and 2, 110 °C elsewhere, cover and shade rule), and a stagnation cover added as BOM line 14.
3. **Response to R12 not met:** option (a). budget_usd changed from **$250 to $320**.

### What changed (before and after)

| Quantity | Before | After |
| --- | --- | --- |
| budget_usd | $250 | $320 |
| Priced BOM | $317.20 (13 lines), $67.20 over | $351.20 (15 lines), $31.20 over |
| R8 rating | 110 °C for all internal materials | 150 °C in stages 1 and 2; 110 °C elsewhere; cover and shade rule |
| R8 status | Not met (140 °C, 144 °C calm) | At risk (144 °C vs 150 °C, 6 K; stage 3 110 °C vs 110 °C in calm air, 0 K) |
| Frame liner | 25 mm PIR foam | 25 mm foil-faced stone wool |
| Panel mass | 15.9 kg dry, 19.9 kg wet | 16.7 kg dry, 20.7 kg wet |
| Wind: lift equals weight | about 17 m/s | about 17.5 m/s |
| Daily distillate, gained output ratio | 10.6 L, 1.26 to 1.34 | Unchanged |

Files changed: `project.yaml`, `README.md`, `docs/01-problem.md` (SSK-PRB-001 v0.4), `docs/02-concept.md` (SSK-PRC-001 v0.4), `docs/03-requirements.md` (SSK-REQ-001 v0.4), `docs/04-calcs/01-sizing.md` (SSK-CAL-001 v0.2) and `sizing.py` (calm-air plate temperatures and R8 check added, budget from DDR-002), `bom/bom.csv` and `bom/bom-notes.md`, `cad/src/model.py` (material notes and liner density; geometry unchanged; STEP and STL re-exported), `cad/src/sheets.py` (SSK-DWG-002 Rev P1 to P2: material block and notes), `cad/src/concept_media.py` (blueprint SSK-DWG-001 Rev P2 to P3: key figures), all media and PDFs regenerated. The README gained the Concept rationale, Burning platform, Where it could be used and What sparked the idea sections.

### Requirement status (not met first)

| Status | Requirements |
| --- | --- |
| Not met | R12 (parts $351.20 against $320) |
| At risk | R8 (0 K margin at stage 3 in calm air; rail polymer not selected), R2 (gained output ratio 1.26 to 1.34 against 1.3), R4 (brine exit over the manifold not detailed), R6 (wick permeability unknown), R7 (coating product not selected), R10 (wick removal not defined) |
| Not verifiable at TRL 3 | R3 (carryover below 8.6 mL per day) |
| Met on paper | R1 (10.6 L), R5, R9 (16.7 kg dry), R11 |

### Still awaiting Amish

1. First co-design partner (coastal NGO, university water lab or makerspace network). No recommendation.
2. Coating product for the condensing faces (R7) and wick fabric (R6). Selections that need datasheets; no recommendation.
3. **Response to R12 not met at $320** (new). Options: (a) raise budget_usd to about $355; (b) keep $320 and cut cost (for example silicone strip rails in stages 1 and 2, a locally sourced cover); (c) exclude the cover and stand from the budget. Recommendation: (a), because the extra cost follows from the decided R8 response. Decided by Amish, 2026-09-26: option (a), budget_usd $355 (SSK-DDR-002 v0.2).

### Cross-repo actions

None. No decision in this repo requires a change to another repo.

### TRL

trl: 3 and trl_target: 3 are unchanged. TRL 4 remains on hold by Amish's instruction: no hardware, tests, purchasing or build-log entries were created. Selecting the rail polymer, coating and wick from datasheets can be done on paper; measuring stagnation temperatures or wick permeability is TRL 4 work and is on hold.

## Session 2026-09-26: sources strengthened

Amish, 2026-09-26: "Fix the weaker sources." All README source links in the Concept rationale, Burning platform, Where it could be used and What sparked the idea sections were fetched and checked against the claims they support.

| Where | Old source | New source |
| --- | --- | --- |
| By country or region: Chile | None (row uncited) | Ruffino et al., "Drinking Water Supply in the Region of Antofagasta (Chile)," IJERPH 19 (2022), [doi:10.3390/ijerph192114406](https://doi.org/10.3390/ijerph192114406). The row now states only what the paper supports: the Atacama is the driest desert in the world, Antofagasta receives about 1.7 mm of rain a year, demand exceeds supply, and about 42 % of the rural population has no formal drinking-water supply. |
| What sparked the idea | Nature Sustainability paper plus ScienceDaily for the 20 L per m2 per day figure | Paper now linked by DOI and cited for its own figure (almost 3 L per m2 per hour at less than one sun); ScienceDaily kept alongside it, labeled as carrying the Politecnico di Torino release, for the 20 L per day figure. Same inspiration event; INSPIRATIONS.md unchanged. |

Links kept after verification: WHO and UNICEF JMP news release (2025), WHO drinking-water fact sheet, World Bank feature on Bangladesh salinity (2015), World Bank blog on South Tarawa, Texas Water Development Board report 363, World Bank blog on MENA water availability. docs/01-problem.md cites no weak source, so its sources are unchanged.

### Budget top-up

Amish, 2026-09-26: "I am ok with the budget top ups." Item 3 of the 2026-09-25 open list is decided as option (a).

| Quantity | Before | After |
| --- | --- | --- |
| budget_usd | $320 | $355 |
| R12 | Not met ($351.20, $31.20 over) | Met ($351.20, $3.80 margin) |

Files changed: `project.yaml`, `README.md`, `docs/01-problem.md` (SSK-PRB-001 v0.5), `docs/02-concept.md` (SSK-PRC-001 v0.5), `docs/03-requirements.md` (SSK-REQ-001 v0.5), `docs/04-calcs/01-sizing.md` (SSK-CAL-001 v0.3) and `sizing.py` (budget 355, rerun), `docs/decisions/0002-recommendations-accepted.md` (SSK-DDR-002 v0.2), `bom/bom-notes.md`, `cad/src/concept_media.py` (blueprint budget line) and the regenerated media. trl: 3 and trl_target: 3 are unchanged.

## Session 2026-09-26: product appearance model and photoreal renders

Amish chose this repo for the first batch of product renders on 2026-09-26. This session added `cad/src/product_model.py`, an appearance model for photoreal renders built on `cad/src/model.py` (PARAMS, `build()`, `rib_positions()` and `wick_strips()`), and pointed the README hero image at `media/render-hero.png` with a link to `media/render-exploded.png`. The render files themselves are produced later by the orchestrator. `model.py`, the BOM and the other docs are unchanged.

### What product_model.py adds

- `product_parts()` (62 parts: 20 shell, 18 internal, 18 accessory including 16 cutaway fills, 6 context), `TITLE` and three `RENDER_VIEWS`: hero (30 deg elevation, az -40), exploded (28 deg, az -55) and detail (52 deg, az -32, no context) looking down into the cutaway.
- Insulated frame shown as a painted plywood shell with eased edges and corner-joint reveals, plus a foil-faced stone wool liner, in the same envelope and with the same condenser lip slots as `model.py`.
- Twin-wall glazing modeled as two skins and webs so the flutes read through the clear sheet.
- A stepped corner cutaway at the front, low corner (local +x, -y) that steps down through the absorber, each stage's wick strips, side rails, silicone ribs and condenser plate, so all four stages are visible. The removed corners are kept as "cutaway fill" parts in group "accessory", so the exploded view shows whole layers.
- Every stack layer as its own part (absorber, four wick layers, four rail pairs, four rib sets, four condenser plates), with rails coloured by material: tan for the 150 degC polymer in stages 1 and 2, kit teal for printed PC in stages 3 and 4.
- Details: glazing trim ring with stainless screws, teal nameplate with raised "STILLSTACK" lettering on the front face, feed trough bead, end caps and drip valve, lidded distillate manifold with parting line, clips, outlet barb and raised "DISTILLATE" label, brine gutter with raised "BRINE" lettering, fins with their 20 mm flange, timber stand with eased edges, front pivot hinges, rear-strut pin holes with a tilt pin, and ground anchor brackets.
- Context (not in the BOM unless noted): a compact ground patch, the silicone outlet tube (BOM 13) to a clear covered distillate container, and the brine drain hose (BOM 10). The stagnation cover (BOM 14) is shown folded as an accessory.

### Differences from model.py (each Proposed, awaiting Amish)

| # | Difference | Recommendation |
| --- | --- | --- |
| 1 | Glazing retention: an anodized aluminum trim ring (1.5 mm, 45 mm wide, with a lip onto the glazing) screwed to the frame top. `model.py` has only the 4 mm frame lip and does not show how the glazing is held. | Adopt a screwed trim or batten over a silicone bead; price it under BOM line 13 or a new line before the next BOM update. |
| 2 | Twin-wall flutes run down the slope at a visual 10 mm pitch. `model.py` shows a plain slab. | Specify flutes down the slope so condensate and rain drain from the channels; take the real pitch from the chosen sheet. |
| 3 | Distillate manifold split into a channel and a lid at the cavity top with clips, and both outlet spouts bored through. `model.py` shows a closed box with solid spouts. | Keep the lid removable for cleaning, as BOM line 9 implies. |
| 4 | Feed trough end caps drawn slightly oversize (76 by 72 mm over the 70 mm gutter) and a drip valve placed on the front (-Y) end cap. `model.py` does not show caps or valve. | Confirm the valve position at the front end, where the user fills and adjusts it. |
| 5 | Fins shown with the 20 mm flange from BOM line 11; `model.py` shows the web only. | Add the flange to `model.py` at the next model update. |
| 6 | Stand hardware (hinges, four pin holes per rear strut, stainless tilt pins, ground anchor brackets) added from BOM line 12. Hole spacing is illustrative and is not derived from the 10 to 35 deg settings. | Derive the hole positions from the tilt check in `model.py` at the next model update. |
| 7 | Nameplate and raised "DISTILLATE" and "BRINE" labels added. | Keep the outlet labels: they help prevent mixing distillate and brine. |
| 8 | Rail colours (tan for stages 1 and 2, teal for 3 and 4) are appearance choices. | Keep a visible colour difference so the high-temperature rails cannot be fitted in the wrong stage. |

The corner cutaway is a render device, not a design change. The wick drape over the high wall into the feed trough is not shown, as in `model.py`.

### TRL

This is an appearance model only: no tolerances, fabrication detail, build procedures or tests. trl: 3 and trl_target: 3 are unchanged, and TRL 4 remains on hold.

## Session 2026-09-27: kit 1.5.0 and image quality

- Kit 1.5.0 synced: STANDARDS v1.5 (sections 12 to 15: product renders, storefront images and image quality, public release, authorship and signing), `.kit/cards.py`, `.kit/image_qc.py`, `.kit/release_gate.py`, issue templates, and the `/render-product` and `/release` commands. `CLAUDE.md` now matches `.kit/CLAUDE.md`.
- Every `media/render-*.png` recaptioned from its original render with the new layout: the title, concept label and repository sit in a band above the render and the view note in a band below it, each line wrapped to the image width, so no text overlaps other text or the render or runs off the image. `media/card.png` and `media/social-preview.png` regenerated with the same rules.
- `python .kit/image_qc.py` and `python .kit/release_gate.py` pass. trl stays 3.

## Session 2026-10-01: kit 1.7.0, design for construction and prototype build plan

Kit 1.7.0 installed (`.kit/`, `.claude/commands/`; `CLAUDE.md` now matches `.kit/CLAUDE.md`). Following `/build-plan` and `.kit/STANDARDS.md` section 18, the concept was checked part by part with build123d and made constructable under Amish's 2026-09-30 instruction ("If you are realising that the design cannot be built as per concept - fix the design assumptions to match and be physically feasible as you draw the illustrations."). Every change is recorded in `docs/decisions/0003-design-for-construction.md` (SSK-DDR-003 v0.1, Draft, open for Amish's review).

### Design changes made for construction

1. **Base ring:** a 12 mm plywood ring under the walls with a 15 mm ledge on all four sides carries the stack; the bottom plate spans between the ledges on its bonded fins (sag 0.5 mm).
2. **Low wall:** a comb with eleven open-topped notches and a removable cap replaces four 1 m slits that left unbuildable slivers; plates drop in from above and lift out again.
3. **Low edge of the plates (proposed, A1):** a zigzag edge with six distillate tongues at the rib lines and corners and five brine tongues at the strip centres; wick tails ride under the brine tongues over the closed manifold lid into the gutter; silicone chevron dams at the brine tongue roots.
4. **Stop blocks:** two blocks of the stage 1 rail polymer in the low corners hold the stack against sliding down the slope.
5. **Glazing:** a 1,060 mm sheet on foam tape on the wall tops, held by a mitred aluminium trim with 7 mm of room to grow; walls 52.5 mm tall.
6. **Feed end:** five openings in the high wall; tails rise behind a silicone foam closure into a trough on two fascia brackets.
7. **Outlets:** two aluminium outlet brackets carry the manifold and the gutter; the manifold lid is slotted only at the six tongue lines.
8. **Fins:** 940 mm long, bonded by their flanges with high-temperature silicone adhesive.
9. **Stand:** ground frame, front posts with plywood gussets and M10 pivot bolts, fixed props (1,000 mm between pins, foot rounded) hinged on blocks and pinned at one of six holes (10 to 35 deg in 5 deg steps); ground rails 760 mm behind the pivot keep the centre of mass inside the frame.
10. **Joints:** glued and screwed wall corners; wicks held by silicone dots; ribs stop 8 mm short of the tongue tips.

### What was done

- `cad/src/model.py`: rebuilt as the constructable model (46 panel parts plus the stand), with `--check` running 93 constructability checks, all passing (overlaps, contacts, 10 mm brine to distillate clearances, stand clashes, centre of mass and footprint at all six tilt holes); STEP and STL re-exported.
- `cad/src/build_plan_media.py` (uses `.kit/build_views.py`): overview, 18 making sketches `cad/drawings/SSK-DWG-101` to `118`, 12 joint close-ups, 22 assembly step pictures, and two layout drawings (plate low edge, end wall openings) in `docs/05-build-plan/`.
- `docs/05-build-plan.md` (SSK-BLD-001 v0.1) and `docs/06-design-decisions.md` (SSK-DEC-001 v0.1).
- `docs/04-calcs/sizing.py` and `01-sizing.md` (SSK-CAL-001 v0.4): wet wick fraction from the zigzag edge, new mass table, stand geometry and hole positions, footprint, cost against the value-engineering target, and a new section of construction checks.
- `bom/bom.csv`: lines 2 to 5, 8, 11 and 12 respecified; lines 15 (glazing trim and tape), 16 (outlet brackets) and 17 (feed closure) added.
- `docs/02-concept.md` (SSK-PRC-001 v0.6), `docs/03-requirements.md` (SSK-REQ-001 v0.6), `docs/decisions/0003-design-for-construction.md`, `project.yaml` (`design_state: constructable`, new evidence), `README.md` (links and "Building the prototype").
- `cad/src/sheets.py`: general arrangement SSK-DWG-002 Rev P3; `cad/src/concept_media.py`: blueprint SSK-DWG-001 Rev P4 and the concept media regenerated.

### Key results

| Quantity | Before | After |
| --- | --- | --- |
| Daily distillate (design day) | 10.6 L | 10.6 L (wet wick fraction 0.824 to 0.817) |
| Panel mass, dry and wet | 16.7, 20.7 kg | 18.5, 22.5 kg (R9 met) |
| Footprint at 10 deg | 1.28 x 1.16 m | 1.28 x 1.25 m (R9 met) |
| Wind speed at which lift equals weight | 17.5 m/s | 18.7 m/s |
| Cost | USD 351.20 | USD 416.20; value-engineering target USD 355, USD 61.20 over the target |
| Low-end vapor loss | not counted | 25 mL per day (0.2 %) |

No requirement is not met. At risk: R2, R4, R6, R7, R8, R10; not verifiable at TRL 3: R3; met on paper: R1, R5, R9, R11; R12 is USD 61.20 over the value-engineering target.

### Proposed, awaiting Amish

All open items are in `docs/06-design-decisions.md`. New from this session: acceptance of SSK-DDR-003 as a whole; A1, the brine exit at the low edge (recommend the zigzag and tongue layout as modelled); A2, feed tails crossing the condensing plates' high edges (recommend accepting for the first prototype and measuring each stage's conductivity at TRL 4).

### Safety concerns

- The brine and feed paths now have defined geometry, but separation of brine from distillate (R4) is still a paper result; the build plan's first checks include a coloured-water test and per-stage conductivity.
- Lifting the panel onto the stand is a two-person job (18.5 kg dry); the stand must be staked or ballasted before the panel faces the sun.
- Stone wool cutting, plate coating and absorber painting need the protective equipment listed in the build plan.

### Stale media (made on Amish's Mac)

The design changed visibly (trim, tongues, comb, trough closure, stand), so `media/render-hero.png`, `media/render-exploded.png`, `media/render-detail.png`, `media/card.png` and `media/social-preview.png` are stale, and `cad/src/product_model.py` still builds the concept (its stand and frame no longer match `model.py`). Regenerate them on Amish's Mac.

### Recommended next step

Amish reviews SSK-DDR-003 and the register. TRL 4 (building and testing to this plan) stays on hold until Amish lifts the TRL 3 cap.

## Session 2026-10-02: open decisions decided

Amish, 2026-10-02: "i approve your recommendations for all 555 open decisions." This approves the recommendation written for every open decision in the design decisions register (SSK-DEC-001). trl stays 3; nothing was built, bought or tested, and TRL 4 remains on hold.

### Decisions recorded (9)

| Register item | Decision |
| --- | --- |
| 1 | SSK-DDR-003 accepted with exceptions: P1 to P12 as made, A2 decided as (c) and P11's silicone dots replaced by wick clips |
| 2 | Zigzag edge brine and distillate tongues (A1 (a)); distillate conductivity test per stage a pass condition at TRL 4 before any water is drunk; cross-wick the fallback |
| 3 | 4 mm downturned lip on each condensing plate's high edge now (A2 (c), changed from the register's (a)); dropped only on test evidence |
| 4 | Wicks held by clips at high and low ends, no adhesive |
| 5 | Lowest-cost coating certified for drinking-water contact and rated 150 °C dry (fluoropolymer cookware coatings first), else 316 stainless plates 1 and 2 |
| 6 | Wick fabric chosen by a wicking-rise test between a polyester-type nonwoven and a glass-fibre fabric |
| 7 | PPS for the stage 1 and 2 rails and stop blocks |
| 8 | University water or desalination lab first; first candidate to approach, the Politecnico di Torino group; coastal NGO later |
| 9 | All five appearance items adopted: flutes down the slope, removable manifold lid, front drip valve, DISTILLATE and BRINE labels, stage 1 and 2 rail colour |

All 9 moved to Decisions made in SSK-DEC-001, dated 2026-10-02; the Open decisions section now reads "None."

### Documents changed

- `docs/06-design-decisions.md` (SSK-DEC-001 v0.2): items 1 to 9 moved to Decisions made; Open decisions reads "None"; "To confirm" item 5 names PPS; the silicone-strip saving marked as not to take
- `docs/decisions/0003-design-for-construction.md` (SSK-DDR-003 v0.2): status accepted with exceptions (kept Draft): A1 accepted, A2 decided as (c), P11 replaced by clips; consequence added
- `docs/decisions/0001-trl2-review-decisions.md` (SSK-DDR-001 v0.2): item 8 ("Proposed, awaiting Amish") recorded as decided
- `docs/decisions/0002-recommendations-accepted.md` (SSK-DDR-002 v0.3): items 4 and 5 (awaiting Amish) recorded as decided
- `docs/03-requirements.md` (SSK-REQ-001 v0.7): R4, R6, R7, R8 and R10 status notes for the decisions; no status changed
- `docs/04-calcs/01-sizing.md` (SSK-CAL-001 v0.5): SSK-DDR-003 accepted; R4, R7 and R10 rows note the decisions; figures unchanged
- `docs/02-concept.md` (SSK-PRC-001 v0.7): coating, PPS, lip, conductivity pass condition in the safety note, open questions answered, partner, labels and rail colours
- `docs/01-problem.md` (SSK-PRB-001 v0.6): partner decided and first candidate to approach
- `docs/05-build-plan.md` (SSK-BLD-001 v0.2): section 2 records the acceptance and its exceptions; PPS rails in their own colour; plate step 4 adds the high-edge lip; wick step 4 uses clips, no adhesive; superseded by the follow-ups carried out below
- `bom/bom-notes.md`: PPS rails, coating rule, wick fabric test, wick clips and labels noted (carried into BOM lines and prices in the follow-ups below)
- PDFs regenerated with `python3 .kit/render.py`; superseded versions removed.

### Follow-up actions to carry approved decisions into the design

The model, BOM quantities and prices, calculations and pictures were not changed in the first part of this session. These actions carry (carried out in the section "Approved follow-ups carried out" below) the approved decisions into them:

1. Decision 3 (model, drawings, build plan pictures): Add the 4 mm downturned lip on each condensing plate's high edge in `cad/src/model.py`, re-run the 93 checks (feed tail clearance at the high edge), and update the plate making sketches (SSK-DWG-110 and the bottom plate sketch) and the joint pictures at the high wall.
2. Decision 3 (calculations): Check the lip's effect on plate blank size, cost and mass in `docs/04-calcs/sizing.py` (a bend, no yield loss expected).
3. Decision 4 (model, drawings, build plan pictures, BOM): Design the wick end clips (stainless, or PPS in stages 1 and 2), add them to the model, the wick cutting sketch SSK-DWG-111, the step pictures and a BOM line with price; remove the silicone-dot method from the build plan's Table 1.
4. Decision 2 and 3 (test plan): Write the TRL 4 distillate conductivity test per stage as a pass condition before any water is drunk; it also decides whether the lip can be dropped.
5. Decision 5 (BOM): Select the coating against the rule (drinking-water contact certified, 150 °C dry; fluoropolymer cookware coatings first) and price it in lines 3 and 5, or move plates 1 and 2 to 316 stainless.
6. Decision 6 (BOM): Run the wicking-rise test on the two shortlisted fabrics and name the chosen fabric in BOM line 4.
7. Decision 7 (BOM): Name PPS in BOM line 6 (stages 1 and 2) and for the stop blocks, with its colour, and reprice from a PPS sheet quote.
8. Decision 9 (pictures, model): Update `cad/src/product_model.py` and the renders on Amish's Mac: flutes down the slope, removable manifold lid, front drip valve, DISTILLATE and BRINE labels, stage 1 and 2 rail colour.
9. Decision 8 (documents): Approach the first candidate partner (the Politecnico di Torino group); nothing is agreed yet.

### Points found in the review

Raised when the recommendations were written (2026-10-01) and kept here so they are not lost:

- R4 is 'at risk' and depends on two open safety details (items 2 and 3). The README already says distillate must be tested before drinking, but its hero image alt text calls StillStack a still 'for drinking water'; that wording should wait for TRL 4 conductivity tests.
- Item 3's register recommendation accepts a known 6 mm path for feed water onto a condensing face in a drinking-water safety case; the conservative choice is the lip now.
- Value engineering: the target is USD 355 against USD 416.20 (USD 61.20 over); one listed saving, silicone strip in place of the 150 °C rails in stages 1 and 2, would undo the R8 materials decision (SSK-DDR-002, item 2) and should not be on the savings list without that note.
- R10 (wicks removable in 30 min) is at risk only because the wick fixing (item 4) is open; the build plan's silicone-dot bonding should not be used until item 4 is decided.

## 2026-10-02: Approved follow-ups carried out

Amish, 2026-10-02: every follow-up action from the open-decision sign-off is approved. trl stays 3; nothing was built, bought or tested; budget_usd is unchanged at 355.

### Follow-ups done (6 of 9)

| # | Follow-up | Done |
| --- | --- | --- |
| 1 | Lip on the high edge, model and pictures | Four 7 mm tabs bent down 4 mm on the rib lines of each condensing plate (bottom plate and plates 1 to 3), with four 4 mm slots in the base ring for the bottom plate's tabs; ribs now start 6 mm inside the high edge. 137 constructability checks pass (93 before). Sketches SSK-DWG-104, 107, 110 (P2) and the new joint picture 13 updated |
| 2 | Lip effect on blank, cost, mass | `sizing.py` section 14: 5 mm of sheet per tab, 140 mm2 and 0.76 g in all; the blank is 1,224 mm long on a 1,250 mm sheet; no change to sheet size or cost |
| 3 | Wick clips | 40 stainless clips (0.4 x 8 mm 304 strip): 20 high-end bars with ears hooked round the plate edge, 20 tongue clips round each brine tongue; no adhesive. In the model, SSK-DWG-111 (P2), new sketches SSK-DWG-119 and 120, joints 13 and 14, steps 6 to 9, BOM line 18 at USD 14.00; silicone dots removed from the build plan |
| 5 | Coating | Fluoropolymer (PTFE or PFA type) cookware coating chosen as the class and kept at the USD 5 per plate allowance (BOM line 5); applied after the lip is bent. No named product: its drinking-water certificate has not been seen, so plates 1 and 2 may still need 316 stainless (register item 8) |
| 7 | PPS | Named in BOM line 6 (natural, tan) for the stage 1 and 2 rails and the stop blocks; stage 3 and 4 rails are teal PC. Repriced at USD 11.50 per rail from a distributor list price of about USD 70 per kg; a sheet quote is still to be obtained (register item 7) |
| 8 | Appearance model | `cad/src/product_model.py` rebuilt from the constructable model (it had broken on parameters that no longer exist); flutes down the slope, removable manifold lid, drip valve at the front end of the trough, DISTILLATE and BRINE labels, PPS and PC rail colours; render scenes exported (hero, exploded, detail) |

### Not done

- 4 (conductivity test plan per stage): TRL 4 work, which the TRL 3 cap forbids.
- 6 (wicking-rise test on two fabrics): a physical test, TRL 4 work; BOM line 4 keeps its indicative price.
- 9 (approach the Politecnico di Torino group): outreach by Amish; nothing agreed.

### Documents changed and new versions

- `docs/05-build-plan.md` SSK-BLD-001 v0.3; `docs/04-calcs/01-sizing.md` SSK-CAL-001 v0.6; `docs/03-requirements.md` SSK-REQ-001 v0.8; `docs/02-concept.md` SSK-PRC-001 v0.8; `docs/06-design-decisions.md` SSK-DEC-001 v0.3; `docs/decisions/0003-design-for-construction.md` SSK-DDR-003 v0.3; `bom/bom.csv` (lines 5, 6, 18, 19), `bom/bom-notes.md`, README (cost, hero alt text).
- Drawings: SSK-DWG-002 Rev P4; SSK-DWG-001 concept blueprint Rev P5; making sketches 104, 106, 107, 109, 110, 111 at P2; 119 and 120 new. Build plan pictures regenerated: overview (22 components), every joint, every step, low-edge layout; joints 13 and 14 are new.
- Model STEP and STL regenerated.

### Results

- Requirement status change: R10 moves from at risk to met on paper (the wicks lift out on clips, in the model; the 30 minute time is to be shown at TRL 4). R4 stays at risk until the TRL 4 conductivity test; R7 stays at risk until a certificate is seen. Five at risk (R2, R4, R6, R7, R8), one not verifiable (R3), five met on paper (R1, R5, R9, R10, R11).
- Value-engineering target: USD 355. Estimated cost of the constructable design: USD 443.20 (USD 88.20 over the target). The USD 27 added: PPS rails at list price USD 10, wick clips USD 14, labels USD 3.
- Panel mass 18.7 kg dry, 22.7 kg wet (R9 met).

### Proposed, awaiting Amish

- The lip is four 7 mm tabs per plate on the rib lines, not a full-width lip. A full-width lip cannot work because each plate's own wick strips pass out through the same edge, and the base ring also needed slots. The tabs guard the gaps between wick strips; they do not stand in the path of a drip from a tail itself. If the conductivity tests show carryover at the strips, the alternatives are the 22 mm stagger (A2 (b)) or letting each wick dip below a full-width lip, which cuts the gap above the plate below from 6 mm to about 3.5 mm at the edge.
- Appearance deviations in `product_model.py` from `model.py`: twin-wall glazing drawn with skins and flutes, trim screw heads, nameplate, drip valve body and lever, label bands and lettering, lid clips, outlet barb, outlet tube, jar and gravel, and a stepped corner cutaway (a render device). The render title no longer says "for drinking water", as the 2026-10-01 review advised, until the TRL 4 conductivity tests.

### Cross-repo actions

None arose from this repo's follow-ups.

### Safety

No change. Distillate stays test water until each stage's conductivity test passes (S7 in the build plan).

### Recommended next step

Amish renders the three views on the Mac (`.kit/photoreal.py` on the scenes in `/home/claude/renders/stillstack`), then `python .kit/cards.py .`; separately, ask a coater for the coating certificate and a distributor for a PPS sheet quote.

## 2026-10-02: photoreal renders redone on the constructable design

Rendered with Blender Cycles on Amish's Mac from the updated appearance model; captioned with `.kit/photo_caption.py`; `media/card.png` and `media/social-preview.png` regenerated with `.kit/cards.py`. Views: hero, exploded, detail. image_qc passes. Appearance deviations are those logged above as proposed, awaiting Amish.

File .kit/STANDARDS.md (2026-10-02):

---
doc_id: OHP-STD-001
title: Documentation and drawing standard
project: Open Hardware Portfolio
doc_type: Standard
version: "1.7"
status: Released
date: 2026-09-30
author: Amish Chadha
license: CC-BY-SA-4.0
revisions:
  - version: "1.0"
    date: 2026-09-24
    author: Amish Chadha
    change: First release of the standard
  - version: "1.1"
    date: 2026-09-24
    author: Amish Chadha
    change: Adopt Technology Readiness Levels (section 9) for project maturity
  - version: "1.2"
    date: 2026-09-24
    author: Amish Chadha
    change: Portfolio phase cap (section 10), concept media standard (section 11), CLAUDE.md guardrails
  - version: "1.3"
    date: 2026-09-24
    author: Amish Chadha
    change: Scale figure, interactive 3D viewer and flow diagrams added to concept media; session slash commands
  - version: "1.4"
    date: 2026-09-26
    author: Amish Chadha
    change: Every sheet and render names the project and its GitHub repository; overall dimensions, ISO centre lines and 300 dpi PNG on sheets; titles name the device and view labels state the viewing direction; optional photoreal renders with Blender
  - version: "1.5"
    date: 2026-09-27
    author: Amish Chadha
    change: Product renders (section 12), storefront images and image quality check (section 13), public release and release gate (section 14), authorship, citation and commit signing (section 15)
  - version: "1.6"
    date: 2026-09-29
    author: Amish Chadha
    change: Licensing metadata with REUSE (section 16), Zenodo DOI and Software Heritage archiving (section 17), release gate checks REUSE and a single CITATION.cff license, archive.py
  - version: "1.7"
    date: 2026-09-30
    author: Amish Chadha
    change: Concept and constructable design states; design decisions register (DEC) kept apart from the build plan; prototype build plan (BLD, section 18) with pictures by component is required TRL 3 evidence; every repo targets TRL 3 during the populate phase; build_views.py; /to-trl3 and /build-plan commands
---

# Documentation and drawing standard

Every project in the portfolio uses this standard, so that each precis, write-up and sketch looks the same and carries its own version history. The standard ships as a kit in each repo's `.kit/` folder. The kit version is in `.kit/KIT_VERSION`.

## 1. Document types and IDs

Every controlled document has a unique ID in the form `PRJ-TYP-NNN`.

- `PRJ` is the three-letter project code listed in section 7.
- `TYP` is the document type code from the table below.
- `NNN` is a sequence number within that project and type, starting at 001.

| Code | Type | Typical file |
| --- | --- | --- |
| PRC | Design precis | `docs/02-concept.md` |
| PRB | Problem statement | `docs/01-problem.md` |
| REQ | Requirements | `docs/03-requirements.md` |
| CAL | Calculation or sizing note | `docs/04-calcs/*.md` |
| DDR | Design decision record | `docs/decisions/*.md` |
| BOM | Bill of materials | `bom/bom.csv` |
| DWG | Drawing or sketch sheet | `cad/drawings/*.svg` |
| BLD | Prototype build plan (section 18) | `docs/05-build-plan.md` |
| DEC | Design decisions register (section 18) | `docs/06-design-decisions.md` |
| TST | Test plan or test report (front matter adds `environment: lab` or `relevant`) | `docs/05-tests/*.md` |

Example: `TBK-PRC-001` is the ThermaBrick design precis.

## 2. Revision scheme

| Artifact | While in draft | When released | Change after release |
| --- | --- | --- | --- |
| Documents | 0.1, 0.2, 0.3 ... | 1.0 | 1.1 for minor edits, 2.0 for a design change |
| Drawings | Rev P1, P2 ... (preliminary) | Rev A | Rev B, C ... |

- Every change to a controlled document adds a row to its revision history before the commit.
- The `version` field in front matter always equals the newest row in `revisions`. The renderer rejects a document where they differ.
- Status is one of `Draft`, `In review`, `Released` or `Superseded`. Draft and In review documents print with a status band on every page.
- Every release is tagged in Git as `<doc_id>/v<version>`, for example `TBK-PRC-001/v1.0`. Drawings are tagged `TBK-DWG-001/revA`.
- Git history is the full audit trail. The in-document revision table is the human-readable summary.

## 3. Document front matter

Every Markdown document under version control starts with this block:

```yaml
---
doc_id: TBK-PRC-001
title: ThermaBrick design precis
project: ThermaBrick
doc_type: Precis
version: "0.1"
status: Draft
date: 2026-09-24
author: Amish Chadha
license: CERN-OHL-S-2.0
revisions:
  - version: "0.1"
    date: 2026-09-24
    author: Amish Chadha
    change: Initial draft
---
```

Quote version numbers so YAML keeps `1.0` as text instead of turning it into a number. List revisions newest last.

## 4. Writing style

- Chicago Manual of Style.
- No em dashes. Restructure the sentence instead.
- Lead each section with its conclusion, then support it.
- SI units throughout, in the form `12 kW`, `450 °C`, `3.2 m`. Imperial values may follow in parentheses.
- Number every figure and table ("Figure 2", "Table 1") and give each a caption.
- State every assumption in the calculation that depends on it.
- Put safety notes in a blockquote starting with **Safety:**.

## 5. Visual identity

| Element | Specification |
| --- | --- |
| Typeface | IBM Plex Sans for text, IBM Plex Mono for code and values (SIL Open Font License, bundled in `.kit/fonts`) |
| Ink | `#111827` |
| Secondary text | `#4B5563` |
| Rules and grid | `#D1D5DB` |
| Accent (one only) | `#0F766E` teal |
| Document page | US Letter, 20 mm margins |
| Drawing sheet | ANSI B landscape (431.8 x 279.4 mm) |
| Footer | Document ID, version, status, license and designmolecule.com on every page |

## 6. Drawing and sketch conventions

- Units are millimeters unless the title block says otherwise.
- Third-angle projection, marked with the symbol in the title block.
- Line weights: visible outlines 0.5 mm, hidden lines 0.25 mm dashed, center lines 0.18 mm chain.
- The title block contains the project, title, drawing number, revision, scale, units, projection, sheet, author, date, material or notes, and license.
- Every sheet and every render names the project and its GitHub repository (from `repo:` in `project.yaml`), at the top of the sheet and in the title block, so a printed or forwarded sheet is never anonymous.
- The drawing title names the device, not only the drawing type (for example "Handheld near-infrared resin scanner: general arrangement").
- Every view label states its scale and viewing direction (for example "Scale 1:1; side elevation looking along +Y"), and every isometric or render states where it is seen from.
- Orthographic views generated with `add_ortho` carry overall dimensions (length and depth on the top view, height on the front view) and ISO 128 centre lines on cylinders; hidden lines are dashed. Tolerances are not shown before TRL 4.
- Sheets are exported as SVG, PDF and a 300 dpi PNG.
- The revision table in the top right of the sheet lists every revision.
- Concept sketches use the same sheet and title block and carry the label "CONCEPT, NOT FOR FABRICATION".
- Geometry comes from `cad/src/*.py` (build123d). Sheets are generated by `.kit/drawing.py` and never edited by hand.

## 7. Project codes

| Code | Project | Code | Project | Code | Project |
| --- | --- | --- | --- | --- | --- |
| TBK | ThermaBrick | PCF | PicoFlow | HLT | HelioLite |
| CCB | CharCube | DRN | DustRunner | TRT | TremorTrace |
| STC | StepCue | FXH | FlexHand | CPD | ColdPod |
| SCL | SunClave | STR | SteamRoot | GGD | GrainGuard |
| SDL | SeedLine | ZBX | ZeerBox | RMS | RootMesh |
| DWD | DewDrive | SSK | StillStack | PPR | PotPress |
| WWT | WaterWatch | LMF | LumaFlow | FCL | FieldCell |
| CNP | ConePro | CVC | CulvertCrawl | EGD | EmberGuard |
| SNF | SnapFrame | CGM | CargoMule | SCM | StepClimber |
| SWC | SwapCell | PLP | PalletPilot | FTK | FlatTrike |
| WWK | WaterWalker | GRR | GrowRider | SSP | SunSpoke |
| SGN | StepGen | PBX | PowerBox | WML | WasteWise-ml |
| WSC | WasteWise Scan | RFE | ReflowEconomy | | |
| OHP | Portfolio-wide | | | | |

## 8. Build and publish

- `python .kit/render.py` checks every controlled document and renders it to `docs/pdf/<doc_id>_v<version>.pdf`.
- `python .kit/drawing.py` (called from each project's `cad/src/sheets.py`) builds drawing sheets as SVG and PDF in `cad/drawings/`.
- The GitHub Action in `.github/workflows/docs.yml` runs the checks on every push and attaches PDFs to a GitHub Release whenever a release tag is pushed.
- Public releases follow section 14: `python .kit/release_gate.py` must pass, and the release tag is `v0.<TRL>.0` (for example `v0.3.0` at TRL 3).

## 9. Technology Readiness Level (TRL)

Each project states its maturity as a Technology Readiness Level on the NASA and US DOE 1 to 9 scale. The TRL rates this specific design, not the underlying technology. A sand battery is commercial elsewhere, but a new sand battery design starts at TRL 2 until evidence shows otherwise.

| TRL | Definition | Evidence the repo must contain |
| --- | --- | --- |
| 1 | Basic principles observed | Problem statement (PRB) |
| 2 | Technology concept formulated | Draft precis (PRC) and requirements (REQ) |
| 3 | Analytical or experimental proof of concept | Calculation note (CAL), working build123d model with STEP export, drawing sheet (DWG), priced BOM with every unit cost filled in, prototype build plan (BLD) with pictures, `design_state: constructable` |
| 4 | Components validated in the lab | Test report (TST) with `environment: lab`, build log entries |
| 5 | Validated in a relevant environment | Test report (TST) with `environment: relevant` |
| 6 | System prototype demonstrated in a relevant environment | Precis at version 1.0 or later with status Released, a drawing at a lettered revision (Rev A or later), and a system-level TST with `environment: relevant` |
| 7 to 9 | Operational demonstration through proven in service | Beyond portfolio scope; claim only with a named deployment partner and evidence |

Rules:

- `project.yaml` records `trl` (current level), `trl_target` (the level the current effort aims for) and `trl_evidence` (the files that support the claim).
- `python .kit/render.py --check` fails if the evidence for the claimed TRL is missing. CI runs this check on every push.
- Documentation alone cannot go past TRL 3. TRL 4 and above require hardware and a test report.
- TRL and visibility are independent. A repo can be public at TRL 3 as a documented design ready to build.
- A change of TRL is recorded in the build log with the date and the evidence that justified it.

## 10. Portfolio phase and TRL cap

`.kit/PHASE.yaml` sets the current phase. During the **populate** phase every repo is capped at **TRL 3**: `trl` and `trl_target` may not exceed 3, and the check fails if they do. Every repo targets the cap: `trl_target` must equal 3, so a new repo is taken all the way to TRL 3 (scaffold, populate and advance, see `/to-trl3`). Work that belongs to TRL 4 or later (building or testing hardware, test articles, test plans and reports, build-log entries, purchasing lists, PCB layouts) must not be started. The prototype build plan (BLD, section 18) is TRL 3 paper work and is required. Where it already exists it is kept, flagged in the check output, and not extended. Only Amish changes `PHASE.yaml`.

Every repo carries a `CLAUDE.md` with the working rules for AI sessions: the TRL cap, decision rights (nothing is recorded as decided unless Amish decided it), one step per session, and a mandatory `docs/REVIEW.md` before stopping.

## 11. Concept media

Every repo at TRL 2 or above explains its idea visually. Media are generated from a build123d massing model with `.kit/concept.py`, never drawn by hand, so they stay in step with the design.

| File | Required | Purpose |
| --- | --- | --- |
| `media/hero.png` | TRL 2+ | Shaded isometric render with a 1.75 m person for scale; the website card image |
| `media/concept-blueprint.png` and `.pdf` | TRL 2+ | Blueprint concept sheet: orthographic and isometric views, scale, key figures, title block |
| `media/model.glb` and `media/viewer.html` | TRL 2+ | Interactive 3D viewer (glTF plus model-viewer) for the website |
| `media/cutaway.png` | When the inside matters | Section view showing internal parts |
| `media/exploded.png` | Recommended | Exploded view with numbered callouts matching the BOM |
| `media/flow.png` | When energy or material moves | System, energy or material flow diagram with losses |

Session commands in `.claude/commands/` (`/populate`, `/advance-trl3`, `/rein-in`, `/refresh-media`) carry the standard prompts, so every Claude Code session starts from the same instructions.

At TRL 2 a massing model is enough: correct overall proportions and main components. All concept media carry "CONCEPT, NOT FOR FABRICATION". The check warns when required media are missing at TRL 2 and fails at TRL 3.

## 12. Product renders

Every repo at TRL 3 shows the product as it would look, not only as a massing model.

- `cad/src/product_model.py` is the appearance model. It defines `product_parts()` (named parts with a shape and a material), `TITLE` ("Name: what it is") and `RENDER_VIEWS`. It is for renders only: every main dimension comes from `cad/src/model.py`, never typed in again.
- Where the appearance model departs from `model.py` (a chamfer, a label, a fastener drawn for realism), record the deviation in `docs/REVIEW.md` as "Proposed, awaiting Amish".
- Scale comes from context, not from a floating figure: a hand or forearm for handheld objects, and the posed mannequin (`mannequin()` in `.kit/context_parts.py`: stand, walk, push, ride, sit, reach) for anything a person uses at body scale.
- Renders are made with `.kit/export_views.py` (one scene per view) and `.kit/photoreal.py` (Blender Cycles), then captioned with `.kit/photo_caption.py`. Files are `media/render-<view>.png`; `media/render-hero.png` is required.
- Every caption names the project, the repository and the viewing direction, and carries "CONCEPT, NOT FOR FABRICATION".
- Captions never sit on the render. `.kit/photo_caption.py` adds a header band (title, concept label, repository) above the render and a footer band (view note) below it, wraps every line to the image width, and steps the font down to a floor before adding a line.
- The README opens with `media/render-hero.png`.
- Software-only and scene repositories (no single product) may use a scene render as the hero instead of a product model.

## 13. Storefront images

Two images, both made from `media/render-hero.png` by `python .kit/cards.py .`:

| File | Size | Purpose |
| --- | --- | --- |
| `media/card.png` | 800 x 800 | Square thumbnail for the organization profile page |
| `media/social-preview.png` | 1280 x 640, under 1 MB | GitHub social preview, shown when a repository link is shared |

- The social preview shows the area, name, one-line description, the first sentence of the pitch, the brand line and the repository address. Design Molecule repos read "Design Molecule · open hardware concept, TRL n"; OpenRatio repos read "OpenRatio · research and educational prototype, TRL n".
- GitHub has no API for the social preview. Upload it under the repository's Settings, Social preview, on release day.
- Regenerate both images whenever `render-hero.png` changes.

### Image quality

Every render, card and social preview must be clear and readable. `python .kit/image_qc.py` checks each one, and the release gate blocks on any failure:

| Check | Rule |
| --- | --- |
| Layout | Made by the current `photo_caption.py` or `cards.py`, which store the text layout in the PNG |
| Text inside the image | Every line at least 1.2 % of the image width from each edge; nothing runs off the side |
| No overlap | No line of text touches another line, and no caption text sits on the render |
| Text size | Render captions at least 1.05 % of the image width in pixel height (17 px at 1600 px); social preview text at least 16 px |
| Resolution | Renders at least 1200 px wide; card 800 x 800; social preview 1280 x 640 and under 1 MB |
| Sharpness | The render is not blurred or upscaled (edge sharpness at least 15 on the `image_qc.py` scale) |

Long titles and notes wrap to more lines rather than shrinking below the floor. The social preview shortens the pitch sentence with an ellipsis only if it cannot fit at the smallest size.

## 14. Public release

A repository goes public only when Amish approves it, and only after `python .kit/release_gate.py` passes. The gate checks:

1. `render.py --check` passes (document control, TRL cap, concept media).
2. Storefront: hero render, card, social preview under 1 MB, README leading with the hero, and every image passing the image quality check (section 13).
3. Issue templates in `.github/ISSUE_TEMPLATE/`: question, build report, design suggestion. The build report template restates that the design is a TRL 3 concept, not released for fabrication (OpenRatio: a research and educational prototype, not a medical device).
4. `CITATION.cff` valid, with an author ORCID.
5. License files match `project.yaml`.
6. No em dashes in the repository's own text.
7. BioMedical and OpenRatio repos use soft, non-clinical wording: "research and educational prototype, not a medical device".
8. No secrets anywhere in the history (gitleaks).
9. No links to sibling repositories that are still private.
10. REUSE files present (`REUSE.toml`, `LICENSES/`, `.github/workflows/reuse.yml`) and `reuse lint` passes (section 16).
11. `CITATION.cff` names exactly one license, because Zenodo rejects a list (section 17).

It warns, without blocking, when the README lacks a Safety heading or a "not for fabrication" statement, when `CITATION.cff` has no DOI yet, and when the README lacks the Zenodo DOI, REUSE or Software Heritage badge, so a person can confirm.

On release day, per repository:

- A signed, annotated tag `v0.<TRL>.0` on `main`.
- A GitHub release with short notes (what it is, TRL, status, licenses, how to cite) and a design pack, `<repo>-v0.<TRL>.0-design-pack.zip`, holding `cad/step`, `cad/drawings`, `docs/pdf`, `bom`, README, licenses and `CITATION.cff`.
- Description from the first sentences of `pitch` (350 characters at most), website `https://designmolecule.com` (OpenRatio: `https://openratio.ai`), topics from `project.yaml`.
- Before the first release, the repository is switched on in Zenodo (section 17), so the release is archived and gets a DOI.
- Visibility switched to public last, after the release exists.
- The social preview uploaded and the organization profile updated with the new cards.
- After the release: the concept DOI written to `CITATION.cff` and a Software Heritage save requested (section 17).

The internal working files (`CLAUDE.md`, `.kit/CLAUDE.md`, `.claude/commands/`, `docs/REVIEW.md`) stay public, and open "Proposed, awaiting Amish" items stay visible as open questions (Amish, 2026-09-27).

## 15. Authorship, citation and signing

- Amish Chadha is the author of every design, ORCID 0009-0000-8079-7141. Commits are authored as Amish Chadha <amish@designmolecule.com>.
- `CITATION.cff` lists Amish (with ORCID) first, then any credited contributors; `CONTRIBUTORS.md` and the README Credits section agree with it.
- `CITATION.cff` names one license: the hardware license (CERN-OHL-S-2.0), or the software license in a software-only repository. The full split between hardware and software licenses lives in `REUSE.toml` and the README. Once the repository is archived, `CITATION.cff` carries the concept DOI in `doi:`.
- Work done with Claude carries the trailer `Co-Authored-By: Claude <noreply@anthropic.com>` (with the model name), and the README Credits section says designs are developed with AI assistance.
- Every commit and tag pushed to GitHub is signed with Amish's SSH signing key, so GitHub shows it as Verified. Commits prepared elsewhere are re-signed on Amish's Mac before they are pushed.
- Once a repository is public, its history is never rewritten.

## 16. Licensing metadata (REUSE)

Every file states its copyright and license in a machine-readable way, following the REUSE Specification 3.3 (https://reuse.software). A repository is set up with:

```
python .kit/archive.py reuse
```

This writes three things and adds the REUSE and Software Heritage badges to the README badge line:

- `REUSE.toml`, built from the licenses in `project.yaml`. Everything is under the hardware license by default. Scripts, firmware, notebooks, web viewers, workflows and agent commands are under the software license. `cad/` and `electronics/` stay under the hardware license even where they are written as Python. The bundled IBM Plex fonts are OFL-1.1 (IBM Corp.). Copyright is "<first commit year> Amish Chadha".
- `LICENSES/`, with the full text of each license used (`reuse download`). The root `LICENSE` and `LICENSE-SOFTWARE` files stay for GitHub's license detection.
- `.github/workflows/reuse.yml`, which runs the REUSE check (fsfe/reuse-action) on every push and drives the README badge.

A new kind of file that falls outside these rules gets a new annotation in `REUSE.toml` rather than a header comment. `reuse lint` must pass before every commit that adds files, and the release gate enforces it.

## 17. Archiving and DOI (Zenodo and Software Heritage)

Every public repository is archived twice, so the design stays citable and retrievable if GitHub changes.

Zenodo (a citable DOI for each release):

1. Amish's Zenodo account is linked to GitHub. Before the first release, Amish switches the repository on in Zenodo (Account, GitHub). Only Amish changes Zenodo or GitHub settings.
2. Run `python .kit/archive.py zenodo`: it makes sure `CITATION.cff` names one license and adds the Zenodo DOI badge, which uses the GitHub repository ID and always points at the latest version. Zenodo reads its metadata (title, authors with ORCID, license, keywords) from `CITATION.cff`, and rejects the whole archive when that file lists several licenses.
3. Publish the GitHub release (section 14). Zenodo archives it within minutes and mints two DOIs: a version DOI for that release and a concept DOI that stands for all versions.
4. Check the Zenodo record: title, author and ORCID, license, keywords. If Zenodo shows "Citation metadata load failed", fix `CITATION.cff`, validate it with cffconvert and publish a new patch release (for example `v0.3.2`); a failed release is never re-used.
5. Run `python .kit/archive.py zenodo --doi <concept DOI>` and commit, so GitHub's "Cite this repository" and every future archive carry the concept DOI. Every later release gets its own version DOI automatically; the concept DOI never changes.

Software Heritage (permanent source archive):

1. After the repository is public, request a save at https://archive.softwareheritage.org/save/ (origin type git, the repository URL). Anonymous requests are limited to about ten an hour, so batches are spread out.
2. The Software Heritage badge on the README resolves once the save is accepted and ingested. Later pushes are picked up by its regular crawl.

OpenRatio repositories follow the same steps when Amish approves their release.

## 18. Prototype build plan (BLD) and the constructable design

### Two design states

A design moves through two states, recorded as `design_state` in `project.yaml`:

- **Concept**: the design shows what the product does and that it works on paper (TRL 2 and the calculations of TRL 3). Parts may be simplified shapes that have never been checked for how they are made or how they join.
- **Constructable**: every part can be made with the stated process and material, and every part fits and fastens to the parts next to it. Nothing is left as a shape that cannot be cut, cast, bent, printed, machined or bought.

A repo reaches TRL 3 only when its design is constructable and its build plan shows how. Writing the build plan is how the design is made constructable: when a part cannot be made or cannot fit as modelled, change the model so it can (Amish, 2026-09-30: "fix the design assumptions to match and be physically feasible"), keep what the concept does, and record every change in a decision record "Design for construction" (DDR) and in the plan. Changes that alter what the product does, its pitch or its safety case are proposed, not made.

### What the build plan is

`docs/05-build-plan.md` (`PRJ-BLD-001`) tells a capable maker how to build the first proof-of-concept prototype, in order, component by component, and shows it in pictures. It is written before anything is built, states "Plan, not yet built" under the title and never claims results. Building and testing to it is TRL 4 work.

### Writing rules

- **Plain English.** Say "the steel plate the jack stands on", not a model parameter or variable name. No code identifiers, function names, parameter names or file paths in the body of the plan. Give sizes as numbers with units ("a 62 mm hole, centred 100 mm up from the bottom edge"). The only place file names appear is the closing "Where the numbers come from" list.
- **Pictures first.** Every component and every assembly step has a picture. A reader should be able to build from the pictures, with the words explaining what the pictures cannot show (order, force, tolerance, checks).
- **By component, in build order.** Each component is made and checked before the step that needs it.
- **Cost is not the focus.** One line in the overview may state the parts cost from the BOM; there is no cost or time section.
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

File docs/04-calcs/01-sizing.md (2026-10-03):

---
doc_id: SSK-CAL-001
title: StillStack sizing calculations
project: StillStack
doc_type: Calculation
version: "0.6"
status: Draft
date: '2026-10-02'
author: Amish Chadha
license: CERN-OHL-S-2.0
revisions:
  - version: "0.1"
    date: 2026-09-25
    author: Amish Chadha
    change: First TRL 3 sizing (stage energy balance, supports, stagnation, wick feed, salt, mass, tilt, cost)
  - version: "0.2"
    date: 2026-09-25
    author: Amish Chadha
    change: Recommendations accepted by Amish (DDR-002)
  - version: "0.3"
    date: 2026-09-26
    author: Amish Chadha
    change: Budget top-up approved by Amish
  - version: "0.4"
    date: 2026-10-01
    author: Amish Chadha
    change: Design for construction (SSK-DDR-003); constructability checks; budget treated as a value-engineering target
  - version: "0.5"
    date: '2026-10-02'
    author: Amish Chadha
    change: "SSK-DDR-003 accepted (2026-10-02); R4, R7 and R10 rows note the decisions; figures unchanged"
  - version: "0.6"
    date: '2026-10-02'
    author: Amish Chadha
    change: "Approved follow-ups carried in: lip tabs, wick clips, PPS rails and stop blocks, labels; mass 18.7 kg dry, cost USD 443.20; R10 moves from at risk to met on paper"
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

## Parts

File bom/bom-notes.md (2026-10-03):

# BOM notes

Prices are indicative TRL 3 estimates by supplier type, not quotes. Line numbers match the callouts in `media/exploded.png`; line 6 is split into two rows by stage, lines 13 (sealant, fasteners and tubing), 14 (stagnation cover) and 19 (labels) are not modeled, and line 18 (wick clips) is shown with the wicks (line 4).

Value-engineering target: USD 355 (`budget_usd` in `project.yaml`, a hypothetical control target, not a limit). Estimated cost of the constructable design: USD 443.20 (USD 88.20 over the target), 20 lines, checked by `docs/04-calcs/sizing.py`, section 13. Panel mass about 18.7 kg dry.

Changes under SSK-DDR-002 (decided by Amish, 2026-09-25, going with the recommendations):

- the four side rails in stages 1 and 2 (line 6) are now a polymer rated to 150 °C or more (PPS or a high-heat polycarbonate copolymer), at an allowance of $9.00 each in place of $3.50 (+$22.00); the product is not yet selected;
- the frame liner (line 2) is foil-faced stone wool in place of PIR, at the same price;
- a stagnation cover (line 14, $12.00) is added;
- the silicone-cord ribs (line 7, $19.20) are now decided.

The largest cost is still the five aluminum plates with coating (lines 3 and 5, $108). Choosing 316 stainless steel plates instead would add roughly $100 to $150 more.

Every part that touches distillate (lines 5, 7, 9 and 13) must be food-contact rated. The rails in stages 3 and 4 may stay printed polycarbonate; ASA and PETG soften below the dry stagnation temperature of stages 1 to 3 (about 110 to 144 °C in calm air).

Carried into the BOM on 2026-10-02 (SSK-DEC-001):

- the stage 1 and 2 rails (line 6) are natural (tan) PPS, 4 rails at $11.50 (+$10.00 over the $9.00 allowance). Basis: a 7 x 70 x 1000 mm length (about 0.66 kg) at about USD 70 per kg list price for natural PPS sheet gives about $46; this is a distributor list price, not a quote, so a sheet quote is still to be obtained (register item 7 to confirm). The two stop blocks are cut from the offcut. The stage 3 and 4 rails are printed in teal polycarbonate so the two kinds never swap;
- the coating (line 5, and the paint in line 3 is unchanged) is a fluoropolymer (PTFE or PFA type) cookware coating applied by a coater to the top face of the four condenser plates, kept at the $5 per plate allowance; the coater must supply an NSF/ANSI 61 or equivalent certificate for hot salty water, rated to 150 °C dry, before the order, otherwise plates 1 and 2 move to 316 stainless (roughly +$100 to $150 for the pair, register item 8); no named product has been verified;
- the wick fabric (line 4) is chosen by a wicking-rise test between a polyester-type nonwoven and a glass-fibre fabric; the test is TRL 4 work, so line 4 keeps its indicative price;
- the wick clips (line 18): 40 of 0.4 x 8 mm 304 stainless strip, bent by hand, 0.35 each ($14.00; one 6 m coil at about $14 retail gives the 5.5 m needed), replacing the silicone dots; no adhesive;
- DISTILLATE and BRINE labels (line 19), 2 at $1.50;
- the lip on each condensing plate's high edge is a bend (no sheet or price change).

Silicone strip in place of the 150 °C rails is not a saving to take, because it would undo the R8 materials decision.

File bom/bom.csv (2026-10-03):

item | qty | spec | supplier | unit_cost_usd | make_buy | notes
1 Glazing | 1 | 6 mm twin-wall UV-stabilized clear polycarbonate, 1.0 x 1.0 m cut sheet, rated to about 120 C | Greenhouse or glazing supplier | 32.00 | buy | Indicative price for a cut sheet; solar transmittance about 0.80 used in CAL-001
2 Insulated frame | 1 | 12 mm exterior plywood (one 1.2 x 0.6 m panel): side walls 1,074 x 52.5 mm, high wall 1,050 x 52.5 mm with five feed openings, low wall comb 1,050 x 45 mm with eleven notches and cap 1,050 x 19.5 mm, base ring of four strips, two stand gussets; 25 mm foil-faced stone wool board liner (rated well above 150 C); exterior paint | Building supplier | 35.00 | make | Material cost only; stone wool replaces PIR under DDR-002; walls, base ring and openings per SSK-DDR-003 (SSK-DWG-101 to 105)
3 Absorber plate | 1 | 0.5 mm 3003 or 1050 aluminum sheet 1.0 x 1.25 m (996 mm body with zigzag low edge and five brine tongues), high-temperature matte black paint on top face | Metal supplier (cut sheet) | 28.00 | buy | Indicative price including paint; larger blank for the brine tongues (SSK-DDR-003, SSK-DWG-112)
4 Wick fabric | 4 | Viscose-polyester or cotton nonwoven, about 1 mm, 1.0 x 1.4 m per stage cut into five strips with feed and brine tails, permeability 3e-11 m2 or more, tolerates 150 C dry | Fabric retailer | 4.50 | buy | Indicative price; permeability not yet known for any candidate fabric (CAL-001 section 8); longer for the tails (SSK-DDR-003)
5 Condenser plate | 4 | 0.5 mm aluminum sheet 1.0 x 1.25 m (996 mm body with zigzag low edge, six distillate tongues, on plates 1 to 3 five brine tongues, and four 4 mm downturned lip tabs on the high edge bent before coating) with a fluoropolymer (PTFE or PFA type) cookware coating on the condensing (top) face: food-contact and drinking-water contact certified, rated to 150 C dry | Metal supplier (cut sheet) plus coating supplier | 25.00 | buy | Indicative: $20 sheet plus about $5 coating allowance (a fluoropolymer cookware coating applied by a coater; the coater must supply an NSF/ANSI 61 or equivalent food-contact certificate for hot salty water before the order, else plates 1 and 2 move to 316 stainless); the lip is a bend with no extra sheet or cost; tongues per SSK-DDR-003 (SSK-DWG-107, 110)
6 Side spacer rail (stages 1 and 2) | 4 | PPS (polyphenylene sulfide) natural (tan) 7 mm sheet cut into 12 x 7 mm strips 1.0 m, rated above 150 C continuous; the two stop blocks (SSK-DWG-106) are cut from the offcut | Engineering plastics supplier | 11.50 | buy | Decided PPS 2026-10-02 (SSK-DEC-001). Basis: a 7 x 70 x 1000 mm length (about 0.66 kg) at about USD 70 per kg list price for natural PPS sheet gives about USD 46 for the four rails; this is a distributor list price, not a quote, so a sheet quote is still to be obtained
6 Side spacer rail (stages 3 and 4) | 4 | 3D-printed polycarbonate rail 1.0 m x 12 x 7 mm, printed in sections, teal filament so it never swaps with the tan PPS rails of stages 1 and 2 | Self (PC filament from an online retailer) | 3.50 | make | About 100 g of PC filament each; stage 3 reaches about 110 C at dry stagnation in calm air; ASA excluded
7 Intermediate spacer rib | 16 | Food-grade silicone round cord, 7 mm, 1.0 m, four per gap at 194 mm pitch | Seal or gasket supplier | 1.20 | buy | Silicone decided by Amish 2026-09-25 (DDR-002): rated well above 150 C and wets poorly
8 Feed trough | 1 | PVC or HDPE gutter section 1.0 m (70 x 70 mm) with end caps, drip valve and two fascia gutter brackets | Hardware store | 14.00 | buy | Indicative price; brackets added for fixing (SSK-DDR-003)
9 Distillate manifold | 1 | Food-grade PP or HDPE channel 1.1 m with lid and silicone outlet tube | Online retailer | 12.00 | buy | Indicative price; food-contact rated
10 Brine gutter | 1 | PVC gutter section 1.1 m with drain hose, outboard of the distillate manifold | Hardware store | 6.00 | buy | Indicative price
11 Heat-rejection fin | 10 | Folded 0.5 mm aluminum strip, 0.94 m x 30 mm fin with 20 mm flange, bonded under the bottom plate with high-temperature silicone adhesive | Metal supplier (flashing roll) | 1.00 | make | Cut from flashing roll or plate offcuts
12 Adjustable tilt stand | 1 | 45 x 45 mm treated timber about 7 m (two ground rails 828 mm with six prop holes, two cross rails 1,074 mm, two posts, two props 1,044 mm, two prop blocks), M10 stainless pivot and prop hinge bolts, two prop pins with wing nuts, four corner brackets, four ground stakes | Building supplier | 28.00 | make | Material cost only; ground frame, posts with gussets and pinned props per SSK-DDR-003 (SSK-DWG-116 to 118)
13 Sealant fasteners and tubing | 1 | NSF/ANSI 51 or 61 silicone sealant, stainless screws, silicone tube | Hardware store | 20.00 | buy | Indicative price; not shown in the model
14 Stagnation cover | 1 | Opaque white or aluminized polyethylene tarpaulin 1.3 x 1.3 m with elastic edge cord and hooks on the frame | Hardware store | 12.00 | buy | Indicative price; fitted whenever the feed runs out or before maintenance (DDR-002); not shown in the model
15 Glazing trim and tape | 1 | Aluminum unequal angle 25 x 20 x 2 mm, four lengths 1,078 mm mitred; silicone foam glazing tape 3 x 30 mm, 4.3 m; breather tape for the glazing flute ends | Metal supplier and glazing supplier | 20.00 | make | Holds the glazing (SSK-DDR-003, SSK-DWG-113); stainless screws under line 13
16 Outlet bracket | 2 | Aluminum flat bar 30 x 4 mm, 240 mm, bent to an L | Metal supplier | 3.00 | make | Carries the distillate manifold and the brine gutter (SSK-DDR-003, SSK-DWG-115)
17 Feed closure | 1 | Closed-cell silicone foam strip 5 x 35 mm, 1.0 m, glued to the trough's inner wall | Seal or gasket supplier | 6.00 | buy | Closes the high wall feed openings around the wick tails (SSK-DDR-003)
18 Wick clips | 40 | 304 stainless strip 0.4 x 8 mm bent by hand: 20 high-end clips (a bar under the wick with an ear each side hooked round the plate edge and over its top face, about 210 mm of strip) and 20 brine-tongue clips (a U round the tongue and the wick tail under it, about 62 mm); no adhesive | Metal supplier (stainless strip coil) | 0.35 | make | Basis: one 6 m coil of 0.4 x 8 mm 304 strip at about USD 14 retail gives the 5.5 m needed for 40 clips; decided 2026-10-02 (SSK-DEC-001, replacing the silicone dots); in the model as the wick clips (SSK-DWG-111)
19 Labels | 2 | DISTILLATE and BRINE labels: UV-stable vinyl or engraved aluminium, 80 x 25 mm, fixed beside the manifold outlet and the brine drain | Sign or label supplier | 1.50 | buy | Appearance item adopted 2026-10-02 (SSK-DEC-001); not shown in the model

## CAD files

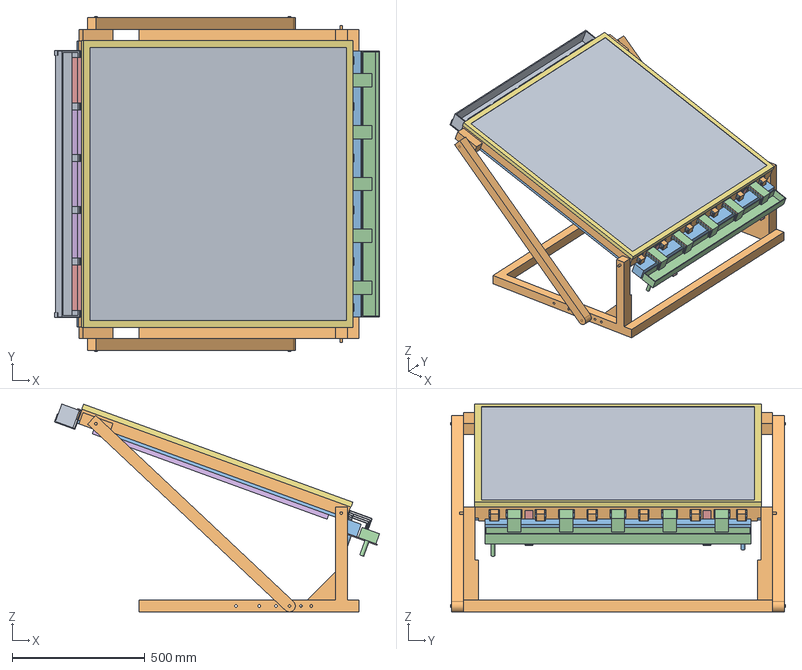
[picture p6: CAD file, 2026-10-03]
cad/step/stillstack-assembly.step
1222.9 x 1260.0 x 782.2 mm
Glazing
Insulated frame
Base ring
Absorber plate
Wicks
Wick clips
Condenser plates
Side spacer rails
Spacer ribs
Feed trough
Feed closure
Distillate manifold
Brine gutter
Outlet brackets
Heat-rejection fins
Glazing trim
Glazing tape
Stack stops
Adjustable tilt stand

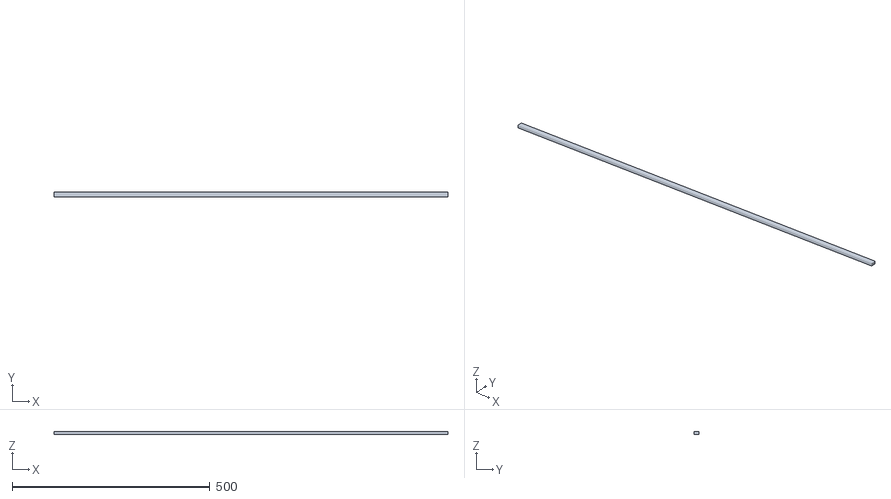
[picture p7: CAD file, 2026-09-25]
cad/stl/side-rail.stl
996.0 x 12.0 x 7.00

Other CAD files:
cad/stl/stillstack-assembly.stl

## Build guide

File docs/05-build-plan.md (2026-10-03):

---
doc_id: SSK-BLD-001
title: StillStack prototype build plan
project: StillStack
doc_type: Build plan
version: "0.3"
status: Draft
date: '2026-10-02'
author: Amish Chadha
license: CERN-OHL-S-2.0
revisions:
  - version: "0.1"
    date: '2026-10-01'
    author: Amish Chadha
    change: First build plan, with pictures by component and step; design made constructable (SSK-DDR-003)
  - version: "0.2"
    date: '2026-10-02'
    author: Amish Chadha
    change: "SSK-DDR-003 accepted with exceptions (2026-10-02): high-edge lip on condensing plates, wick clips in place of silicone dots, PPS rails in their own colour"
  - version: "0.3"
    date: '2026-10-02'
    author: Amish Chadha
    change: "Approved follow-ups carried into the design: lip tabs and base ring slots, wick clips (two new making sketches and two new joint pictures), PPS rails and stop blocks, fluoropolymer coating, labels; every picture regenerated from the model"
---

# StillStack prototype build plan

**Plan, not yet built.** How to build the first proof-of-concept prototype, component by component. Building and testing to it is TRL 4 work. Decisions still to be made are kept in the design decisions register ([docs/06-design-decisions.md](06-design-decisions.md)), not here.

## 1. What you are building

Figure 1. Every component, pulled apart and numbered in build order

*Figure 1. Every component pulled apart and numbered in build order, with the panel at 20° on its stand.*

The prototype is one 1 m2 StillStack panel on its tilting stand. The panel is a shallow plywood box lined with stone wool, closed by twin-wall glazing under an aluminium trim. Inside it lies the stack: a black absorber plate on top, three condenser plates and a bottom plate below it, with a cloth wick clipped under each of the top four plates and 6 mm gaps held by plastic rails and silicone cords. Feed water runs from a trough at the high edge into the wicks; at the low edge, tongues cut from the plates lead distillate into a lidded manifold and brine into a gutter beyond it. Figure 1 shows the 22 components in the order you make or fit them. Most are made in a small workshop: the plywood walls, base ring and stand, the five aluminium plates and the fins, the rails, wicks, trim and brackets. The glazing, liner board, silicone cord, gutters, manifold, fixings and sealant are bought and cut or drilled. The work is sawing and drilling plywood and timber, cutting and folding thin aluminium sheet with snips, cutting fabric and board, a little 3D printing, and sealing with silicone. The parts cost about USD 416 from the bill of materials.

> **Safety:** In sun the absorber passes 80 °C, and about 140 °C if the wicks run dry. Build indoors or in shade, keep the stagnation cover on whenever the panel faces the sun without feed water, and never touch the glazing or open the stack in sun. Cut aluminium edges are sharp: deburr everything and wear gloves. Stone wool sheds fibres: cut it with gloves, glasses and a dust mask. The distillate is not drinking water until it has been tested (section 6).

## 2. What changed to make it buildable

The concept showed what the still does; some of its parts could not be made, fixed or put together as drawn. Each change below keeps what the still does, and all of them are recorded in decision record SSK-DDR-003, which Amish accepted on 2026-10-02 with two exceptions, both now in the model and the pictures: a 4 mm downturned lip on each condensing plate's high edge, and clips in place of the silicone dots for the wicks (sections 3.7, 3.10 and 3.11).

*Table 1. Changes from the concept.*

| Component | The concept had | The buildable design has | Why |
| --- | --- | --- | --- |
| Stack support | A thin ledge along the two side walls only | A plywood base ring under all four walls with a 15 mm ledge; the bottom plate spans between the ledges on its bonded fins (Figure 16) | The whole stack is carried; the bottom plate sags about 0.5 mm |
| Low wall | Four 1 m long, 2 mm slits for the plate lips, leaving slivers of plywood | A comb with eleven open-topped notches and a separate cap strip (Figure 6) | Each plate drops in from above; lifting the cap lets the plates out again |
| Low edge of the plates | Full-width lips, with the brine exit not worked out | A zigzag edge: distillate tongues at the rib lines and corners, brine tongues at the strip centres carrying the wick tails over the closed manifold lid (Figures 21 and 22) | Brine and distillate never share an edge; every brine path keeps 10 mm or more from every distillate path |
| Stack against sliding | Nothing; the plates faced soft stone wool | Two stop blocks in the low corners of the liner (Figure 11) | A hard face for the stack's down-slope load |
| Glazing | A sheet the size of the opening, held by nothing | A larger sheet on foam tape on the wall tops, under a screwed aluminium trim (Figure 30) | Room to grow 4.8 mm when hot; no shade on the aperture |
| Feed | Wicks draped over a solid high wall into a loose trough | Five openings in the high wall; tails rise behind a foam closure into a trough on two brackets (Figure 4) | Feed reaches each stage; vapor stays in |
| Manifold and gutter | No support | Two outlet brackets on the low wall (Figure 34) | The gutter sits lower and further out than the manifold |
| Stand | Vertical rear struts that could not follow the panel's high edge as the tilt changes | Ground frame, front posts with gussets, a pivot bolt, and fixed props pinned at one of six holes (Figures 35 to 40) | Rigid at every tilt from 10° to 35°; the panel's weight stays well inside the frame |
| Plate high edge | Plain edge, with feed tails leaving 6 mm above the condensing face of the plate below | Four 7 mm tabs bent down 4 mm on each condensing plate's high edge, on the rib lines, with slots in the base ring for the bottom plate's tabs (Figure 26) | Gives feed water at the high edge a drip edge away from the condensing face; the wicks pass between the tabs |
| Wick fixing | Wicks bonded under the plates | Two stainless clips per wick strip, one at the high edge and one on the brine tongue, with no adhesive (Figures 24 to 27) | The wicks lift out for rinsing; no adhesive on the wet side |
| Fins, corners, ribs | No fixing method | Fins bonded with silicone adhesive; corners glued and screwed; ribs stopped 6 mm short of the high edge and 8 mm short of the tongue tips | Plain workshop methods |

## 3. Making the components

Make and check each component before the assembly step that needs it. Sizes are in millimetres. "High end" is the feed end (up the slope), "low end" is the outlet end; "across" means across the slope, measured from the centre line. Workshop tolerance is 1 mm on plywood and timber and 0.5 mm on the plates and rails unless a step says otherwise; drawings do not carry tolerances before TRL 4.

### 3.1 Side walls (make 2: a left and a right)

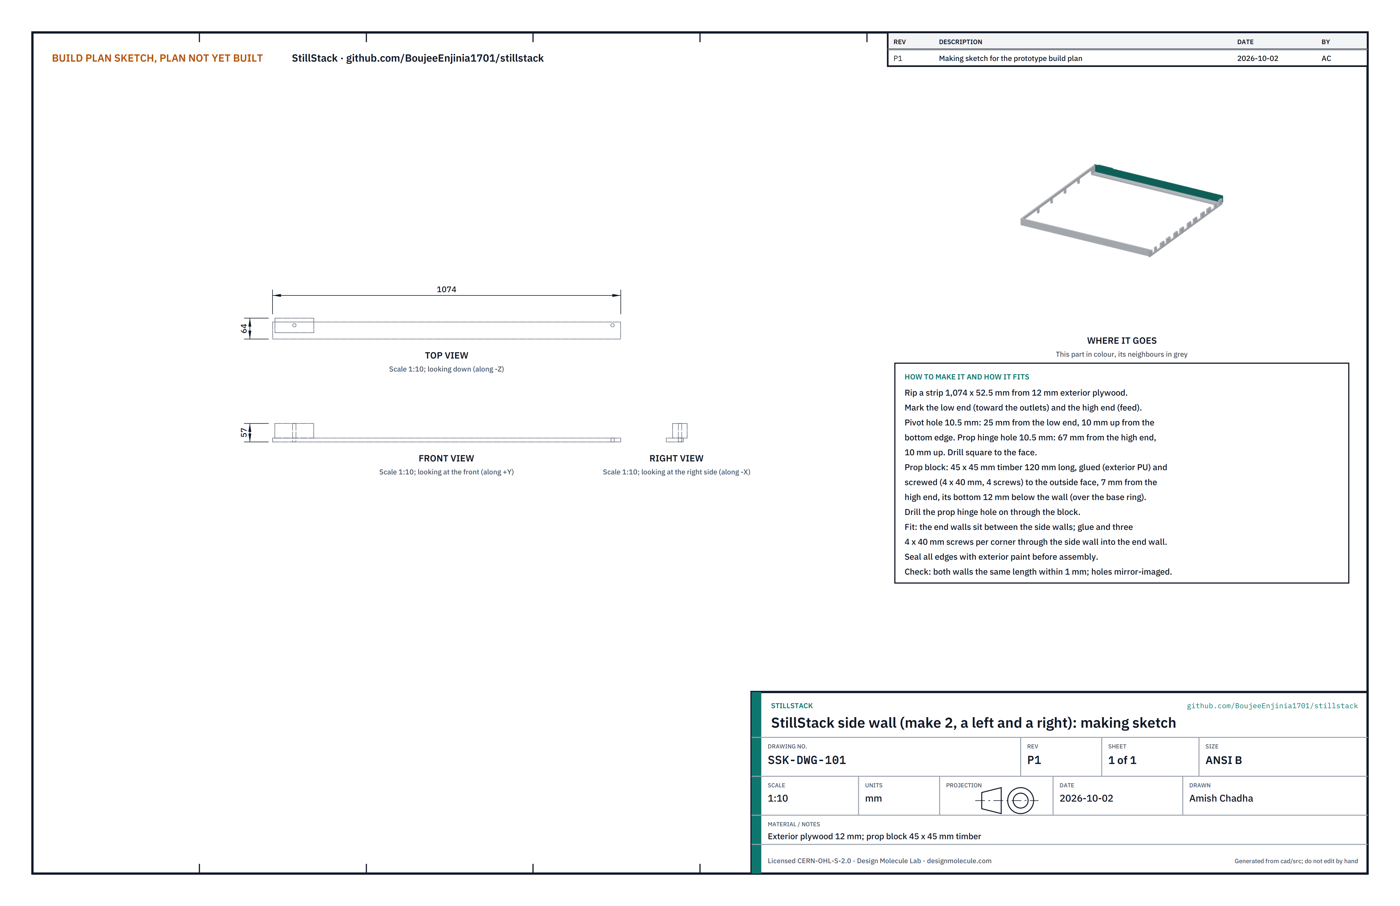
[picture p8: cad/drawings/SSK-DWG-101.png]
Figure 2. Making sketch of the side wall


*Figure 2. Side wall making sketch (SSK-DWG-101), with its prop block.*

**What it is and what it is made from.** The two long sides of the box. Each carries the front pivot near its low end and a prop block near its high end. Exterior plywood 12 mm; prop block 45 x 45 mm treated timber.

**How to make it.**

1. Rip two strips 1,074 x 52.5 mm from the plywood panel. Mark the low end and the high end on each, and make one a mirror of the other.
2. Pivot hole: 10.5 mm, 25 mm from the low end and 10 mm up from the bottom edge. Drill square to the face.
3. Prop block: cut 120 mm of 45 x 45 mm timber. Glue it (exterior polyurethane) and screw it (four 4 x 40 mm screws) to the outside face, 7 mm from the high end, with its bottom 12 mm below the wall's bottom edge so it also covers the edge of the base ring.
4. Prop hinge hole: 10.5 mm, 67 mm from the high end and 10 mm up, through the wall and the block together.
5. Seal all edges with exterior paint.

**How it fits the parts next to it.**

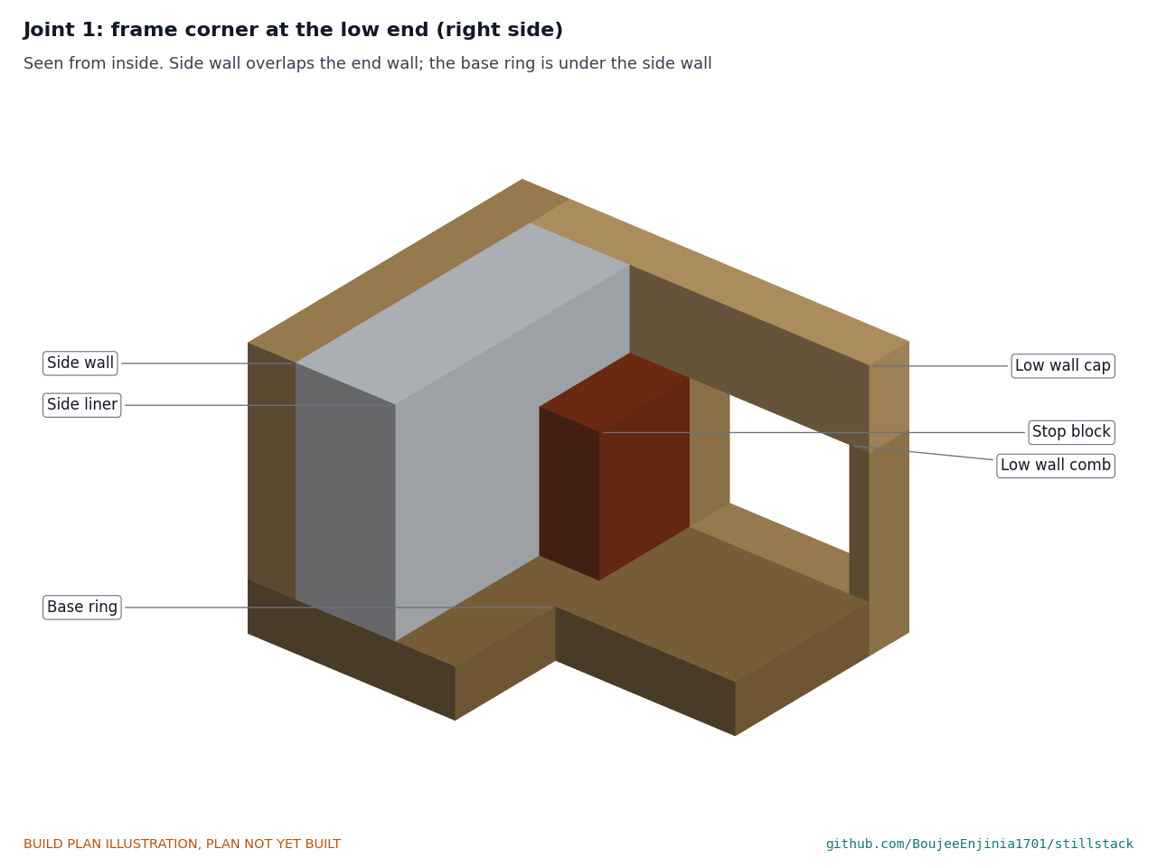
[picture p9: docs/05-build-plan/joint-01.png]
Figure 3. Joint 1: frame corner at the low end


*Figure 3. The side wall overlaps the end of the low wall; the base ring runs under it.*

The high wall and the low wall comb sit between the side walls. Each corner is glued and fixed with three 4 x 40 mm screws through the side wall into the end wall. The base ring is screwed up into the bottom edges, and the glazing trim later ties the tops.

**Check before moving on.** Both walls are the same length within 1 mm, and the holes are mirror images.

### 3.2 High wall (feed end)

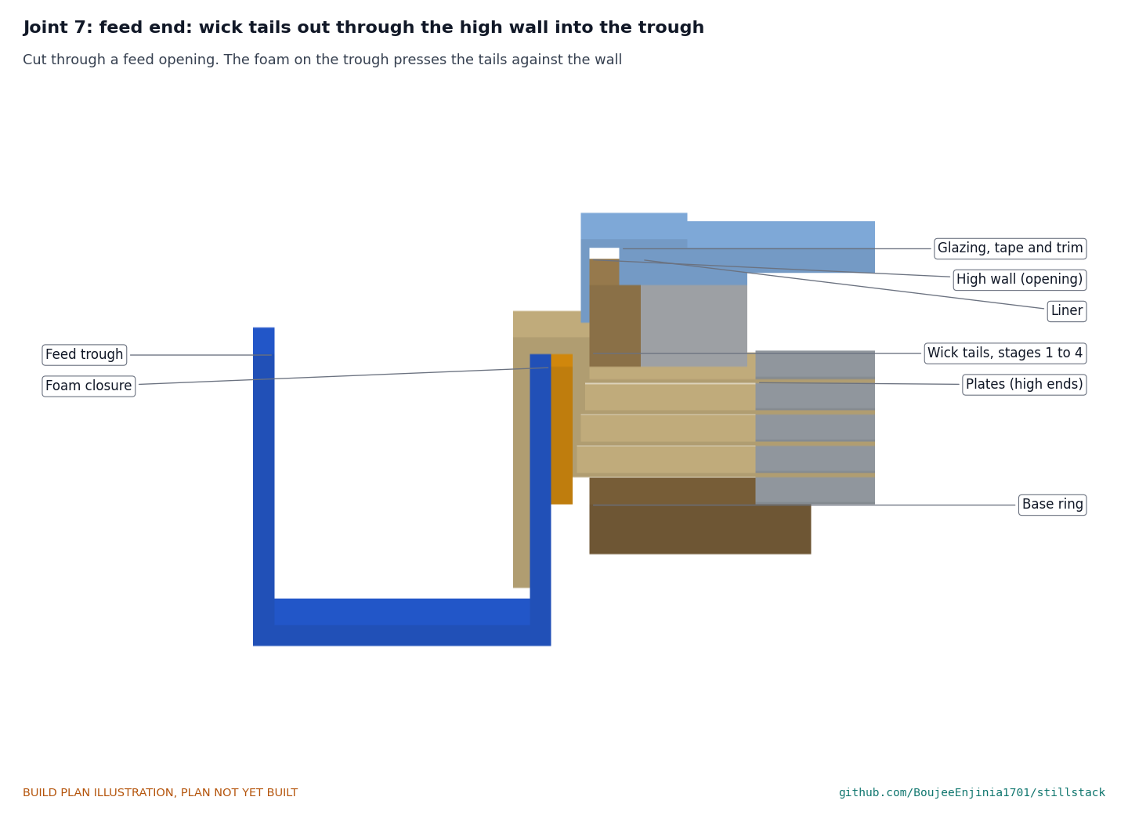
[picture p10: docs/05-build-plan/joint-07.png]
Figure 4. Joint 7: feed end, cut through a feed opening


*Figure 4. The wick tails leave through an opening in the high wall, rise behind the foam closure and drop into the trough.*

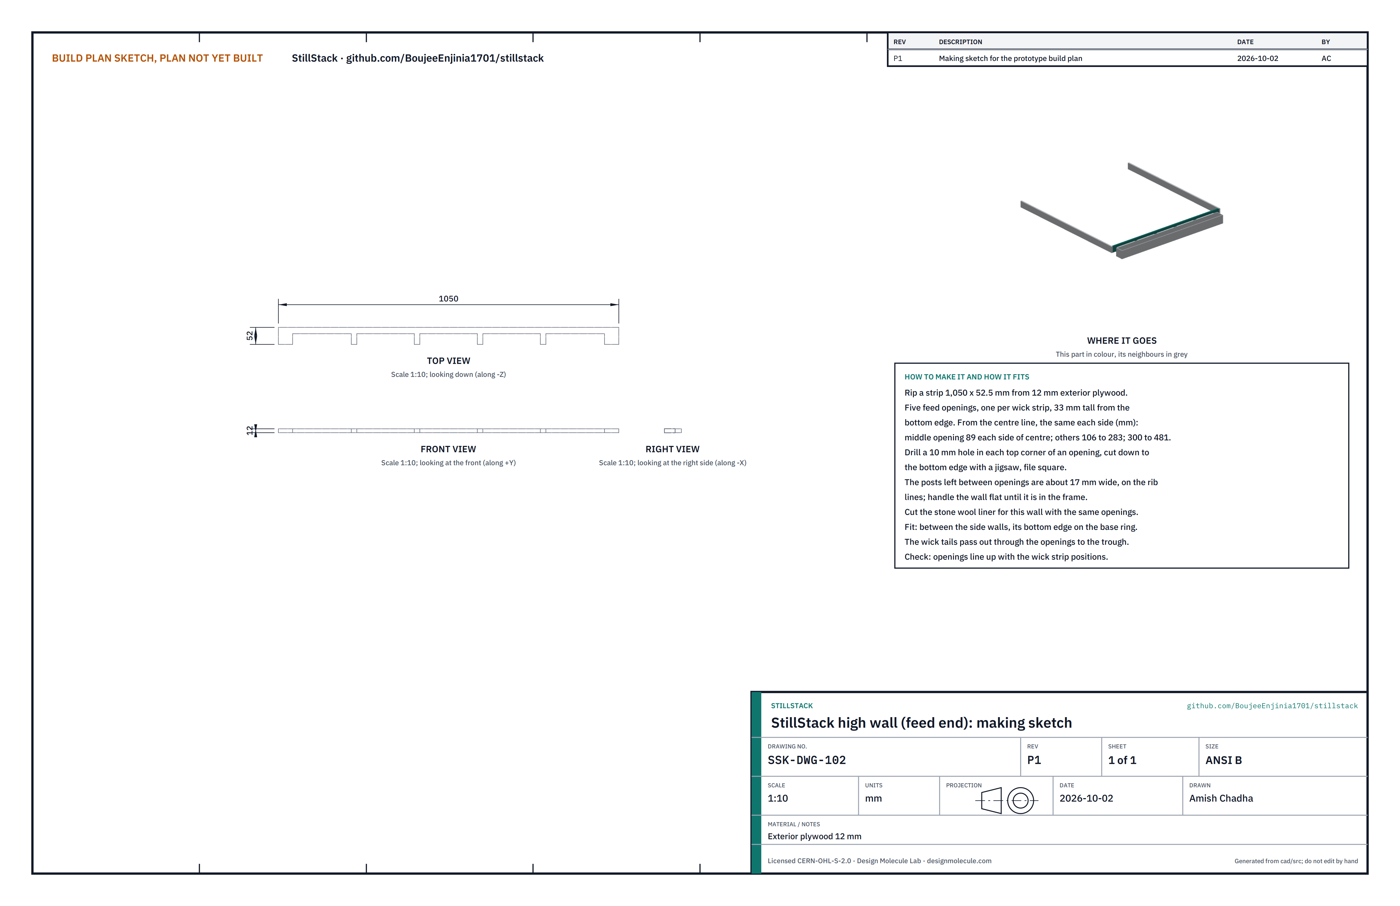
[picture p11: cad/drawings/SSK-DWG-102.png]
Figure 5. Making sketch of the high wall


*Figure 5. High wall making sketch (SSK-DWG-102). Figure 7 gives every opening position.*

**What it is and what it is made from.** The wall across the high end, with one opening for each of the five wick strips. Exterior plywood 12 mm.

**How to make it.**

1. Rip a strip 1,050 x 52.5 mm.
2. Mark five openings 33 mm tall from the bottom edge, as Figure 7 shows: the middle one 89 mm each side of the centre line, the others from 106 to 283 mm and from 300 to 481 mm each side.
3. Drill a 10 mm hole in each top corner of an opening, cut down to the bottom edge with a jigsaw and file square. The posts left between openings are about 17 mm wide; handle the wall flat until it is in the frame.

**How it fits the parts next to it.** It stands between the side walls on the base ring. The tails of all four wicks pass out through its openings (Figure 4); the trough hangs on two brackets screwed to its solid ends, outside the outermost openings.

**Check before moving on.** Each opening lines up with a wick strip position (Figure 7).

### 3.3 Low wall comb and cap (outlet end)

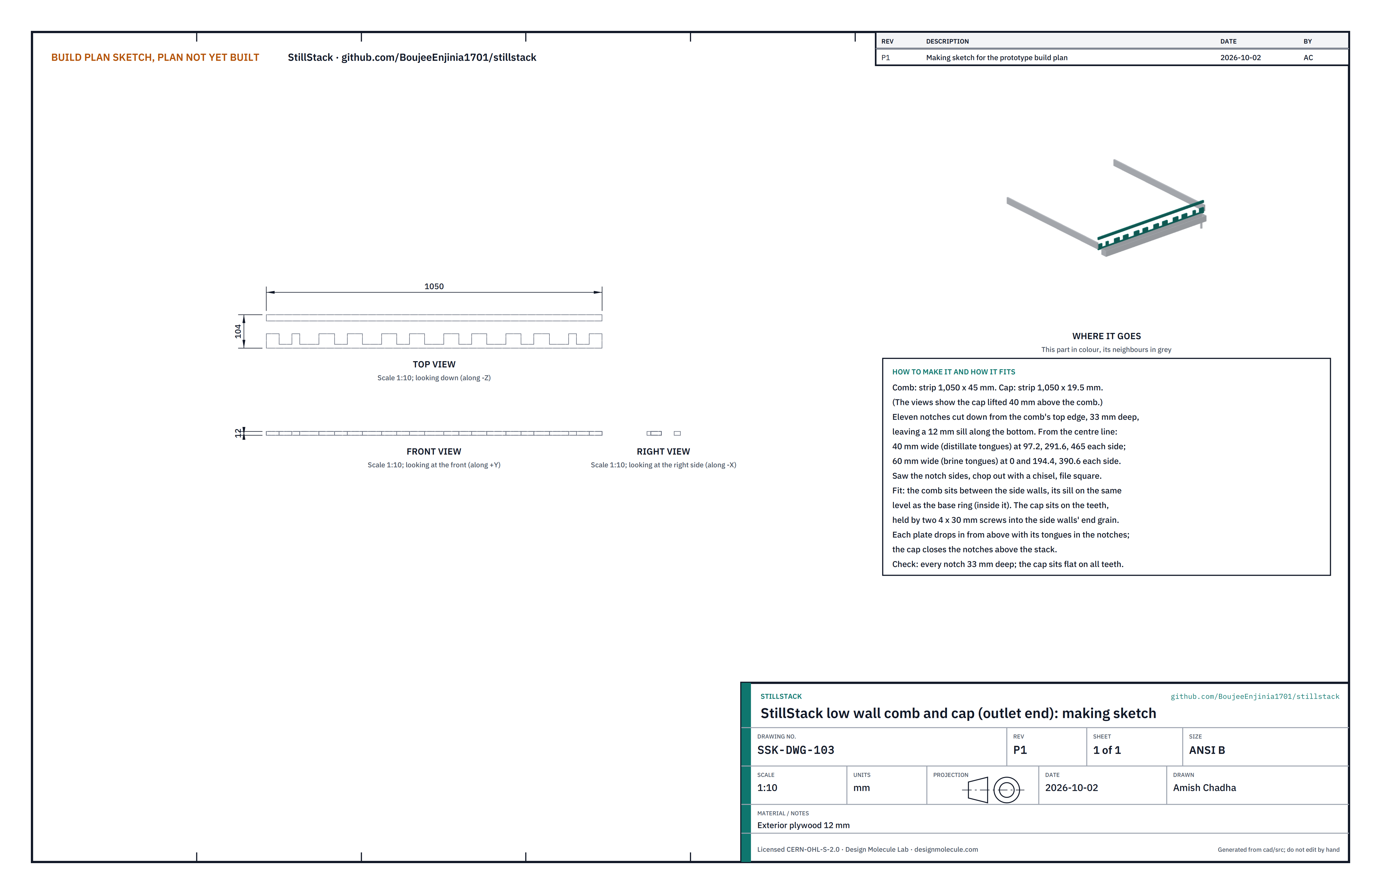
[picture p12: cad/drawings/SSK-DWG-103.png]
Figure 6. Making sketch of the low wall comb and cap


*Figure 6. Low wall comb and cap making sketch (SSK-DWG-103); the cap is drawn lifted above the comb.*

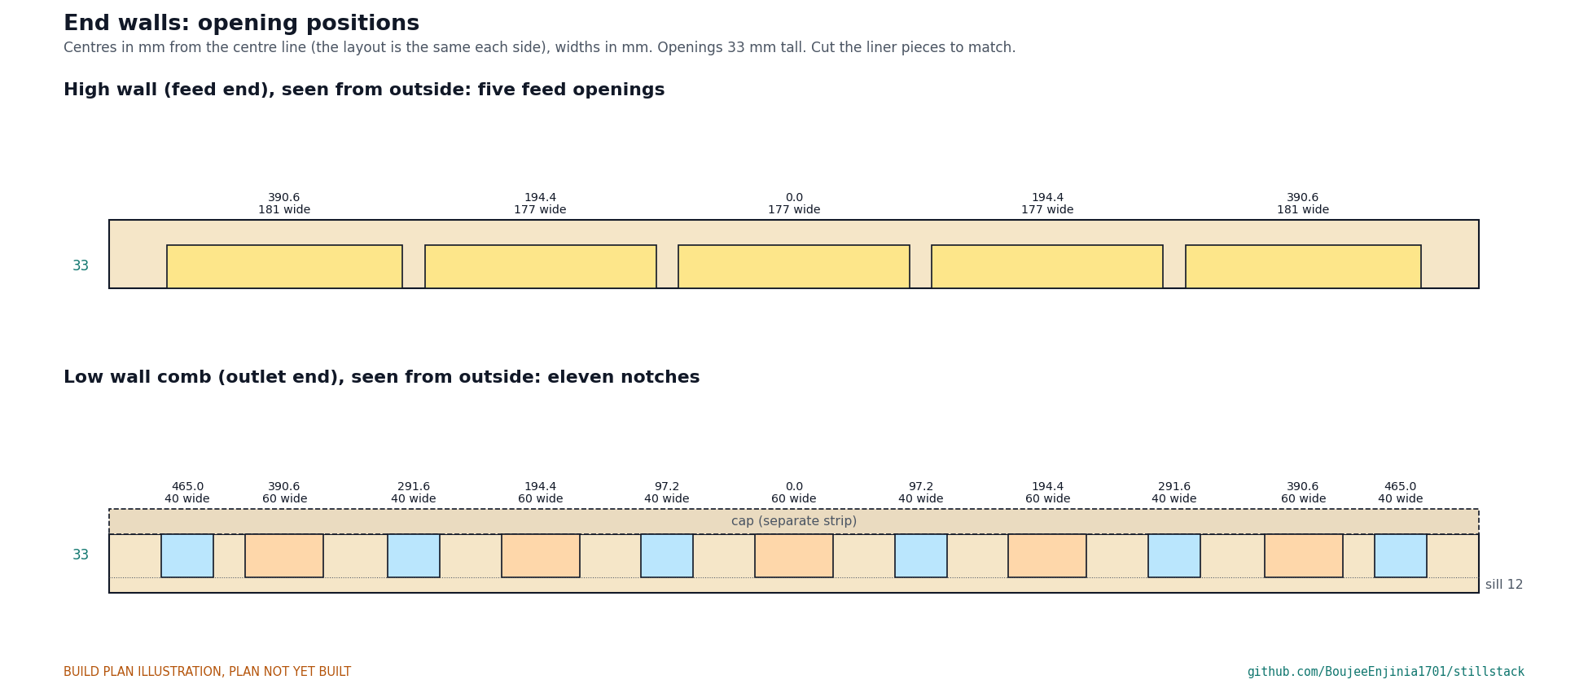
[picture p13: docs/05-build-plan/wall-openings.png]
Figure 7. Opening positions in the high and low walls


*Figure 7. Every opening and notch in the end walls, seen from outside.*

**What it is and what it is made from.** The wall across the low end, made in two pieces so the plates can drop in from above: a comb, whose notches take the plate tongues, and a cap that closes the notches above the stack. Exterior plywood 12 mm.

**How to make it.**

1. Comb: rip a strip 1,050 x 45 mm. Cap: rip a strip 1,050 x 19.5 mm.
2. Mark eleven notches on the comb, cut down from its top edge, 33 mm deep, leaving a 12 mm sill along the bottom (Figure 7): six 40 mm wide for the distillate tongues, centred 97.2, 291.6 and 465 mm each side of the centre line; five 60 mm wide for the brine tongues, centred on the centre line and 194.4 and 390.6 mm each side.
3. Saw the sides of each notch, chop out the waste with a chisel and file square.

**How it fits the parts next to it.** The comb stands between the side walls, its sill level with the base ring and outside it. Each plate's tongues drop into the notches; the bottom plate's tongues rest on the sill. The cap sits on the teeth over the stack and is held by two 4 x 30 mm screws into the side walls' end grain, so it can be lifted off.

**Check before moving on.** Every notch is 33 mm deep; the cap sits flat on all the teeth.

### 3.4 Base ring

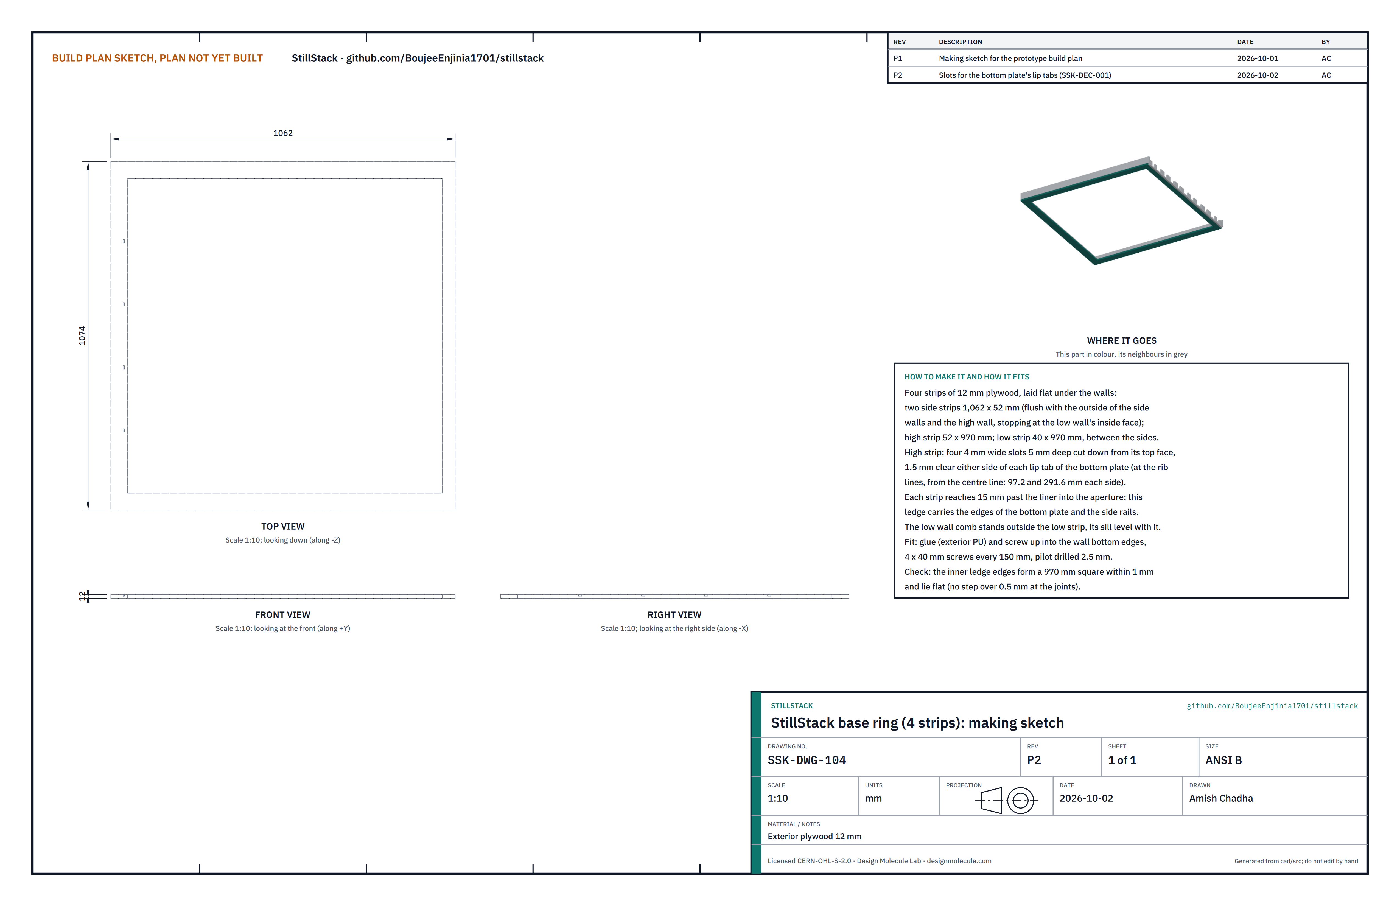
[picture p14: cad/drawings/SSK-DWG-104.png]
Figure 8. Making sketch of the base ring


*Figure 8. Base ring making sketch (SSK-DWG-104).*

**What it is and what it is made from.** Four flat strips under the walls. Their inner edges stand 15 mm into the aperture as a ledge that carries the stack. Exterior plywood 12 mm.

**How to make it.**

1. Cut two side strips 1,062 x 52 mm, one high strip 52 x 970 mm and one low strip 40 x 970 mm.
2. Pilot drill 2.5 mm every 150 mm along each strip's centre line.
3. In the high strip, cut four slots 4 mm wide and 5 mm deep down from the top face, centred 97.2 and 291.6 mm each side of the centre line (the rib lines), so the bottom plate's lip tabs have room. Saw the two sides and chisel out.

**How it fits the parts next to it.** The side strips lie flush with the outside of the side walls and the high wall and stop at the inside face of the low wall comb. The high and low strips fit between them. Glue and screw (4 x 40 mm) up into the wall edges.

**Check before moving on.** The inner ledge edges form a 970 mm square within 1 mm and lie flat, with no step over 0.5 mm at the joints.

### 3.5 Stone wool liner

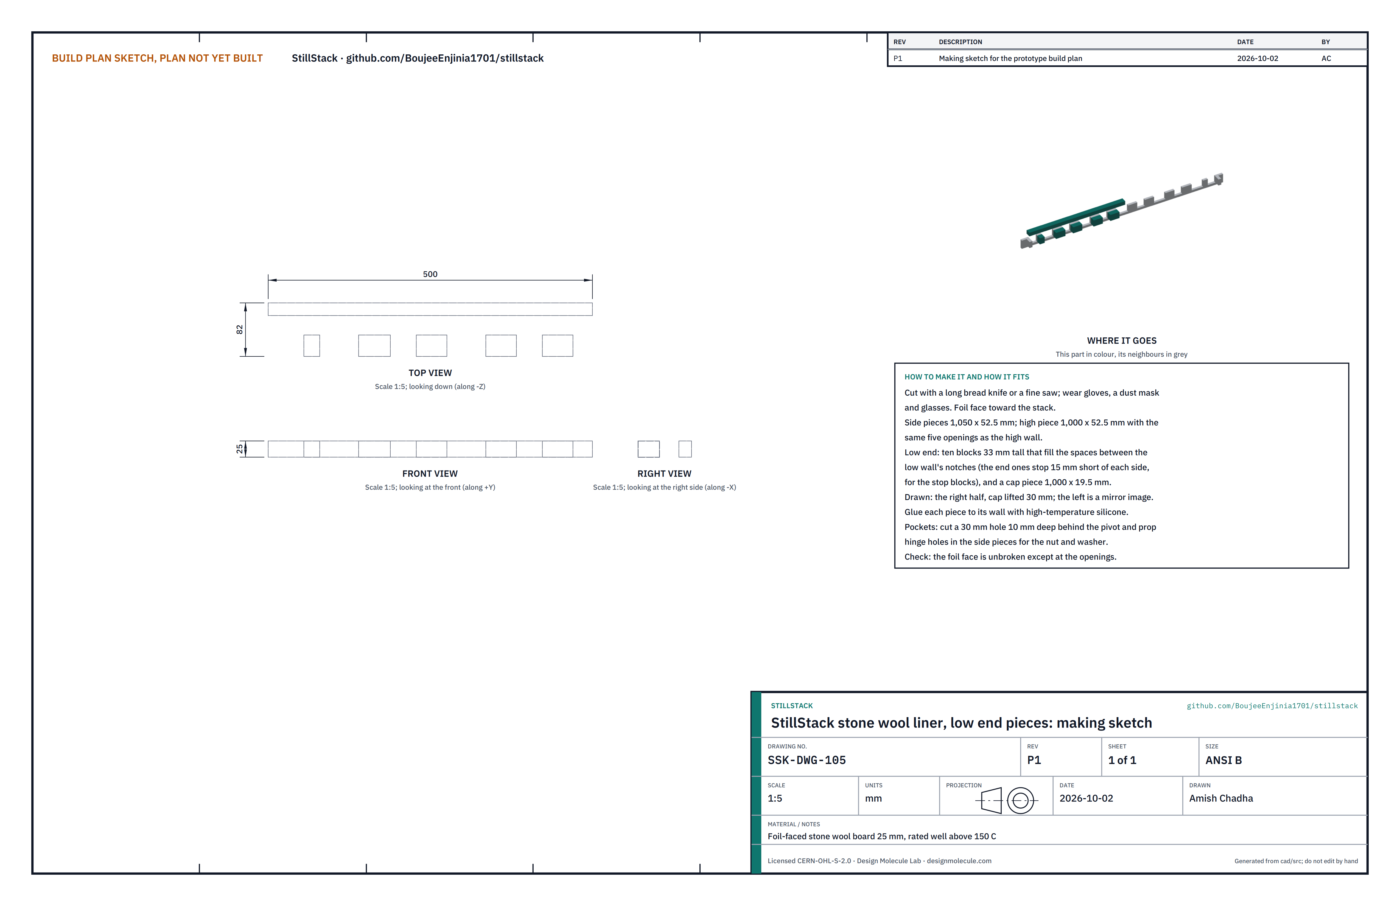
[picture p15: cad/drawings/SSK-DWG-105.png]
Figure 9. Making sketch of the liner's low end pieces


*Figure 9. Liner making sketch, low end pieces (SSK-DWG-105); right half drawn, cap piece lifted.*

**What it is and what it is made from.** Insulation inside the walls. Foil-faced stone wool board 25 mm, rated well above 150 °C.

**How to make it.**

1. Cut with a long bread knife or a fine saw, foil face toward the stack: two side pieces 1,050 x 52.5 mm; a high piece 1,000 x 52.5 mm with the same five openings as the high wall; ten low blocks 33 mm tall that fill the spaces between the low wall's notches (Figure 7); and a low cap piece 1,000 x 19.5 mm.
2. In each side piece, cut a pocket 30 mm across and 10 mm deep behind the pivot hole and the prop hinge hole, for the nut and washer.

**How it fits the parts next to it.** Each piece is glued to its wall with high-temperature silicone, its bottom on the base ring. The two end blocks stop 15 mm short of each side to leave room for the stop blocks; the cap piece is glued to the cap.

**Check before moving on.** The foil face is unbroken except at the openings and pockets.

### 3.6 Stop blocks (make 2)

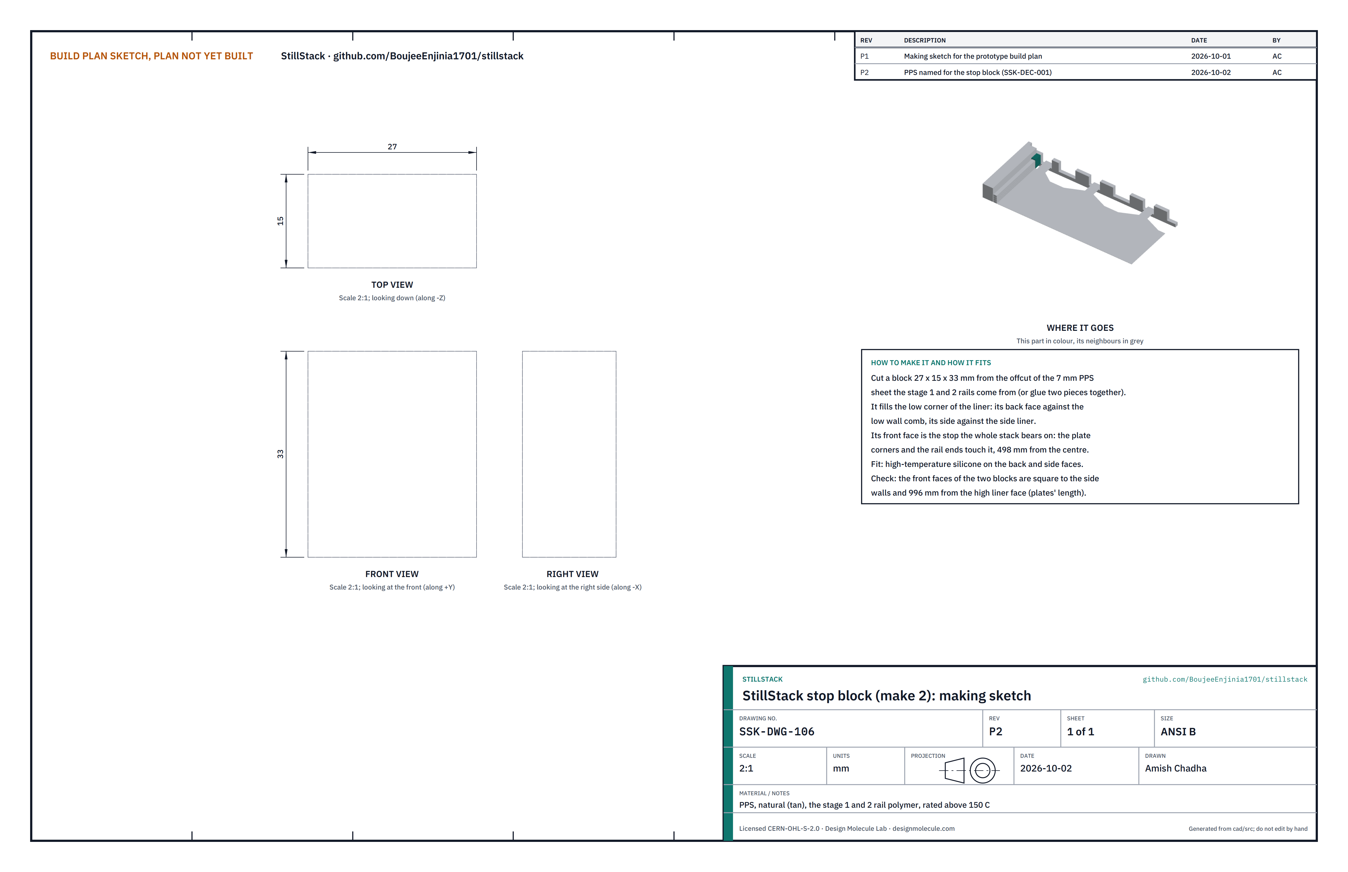
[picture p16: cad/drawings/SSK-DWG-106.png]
Figure 10. Making sketch of the stop block


*Figure 10. Stop block making sketch (SSK-DWG-106).*

**What it is and what it is made from.** A block in each low corner that the whole stack bears on, so it cannot slide down the slope. PPS, natural (tan), the stage 1 and 2 rail polymer, rated above 150 °C (decided 2026-10-02).

**How to make it.** Cut a block 27 x 15 x 33 mm from the offcut of the 7 mm PPS sheet the stage 1 and 2 rails come from, or glue two pieces of it together with high-temperature silicone.

**How it fits the parts next to it.**

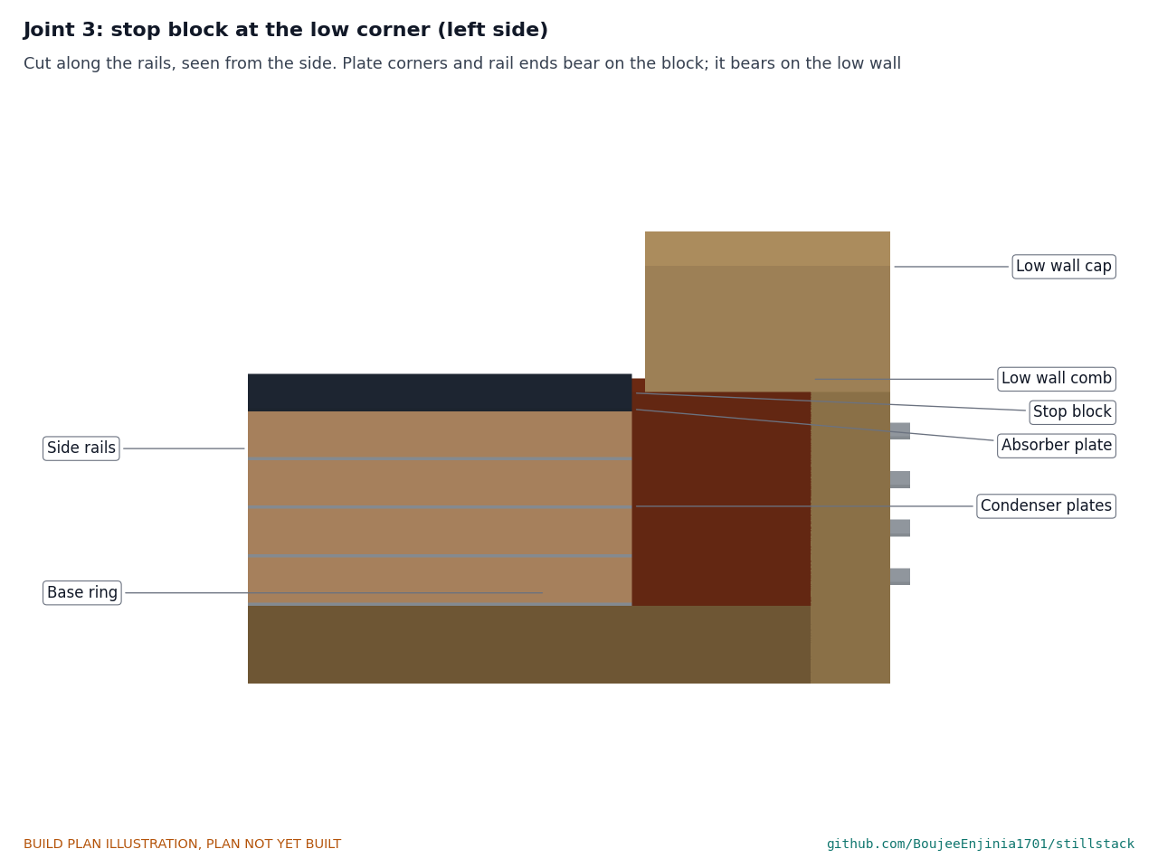
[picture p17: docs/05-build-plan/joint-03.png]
Figure 11. Joint 3: stop block at the low corner


*Figure 11. Cut along the rails: the plate corners and rail ends bear on the block, and the block bears on the low wall.*

The block fills the liner's low corner: its back against the low wall comb, its side against the side liner, glued with high-temperature silicone. Its front face is 996 mm from the high liner face, the length of a plate.

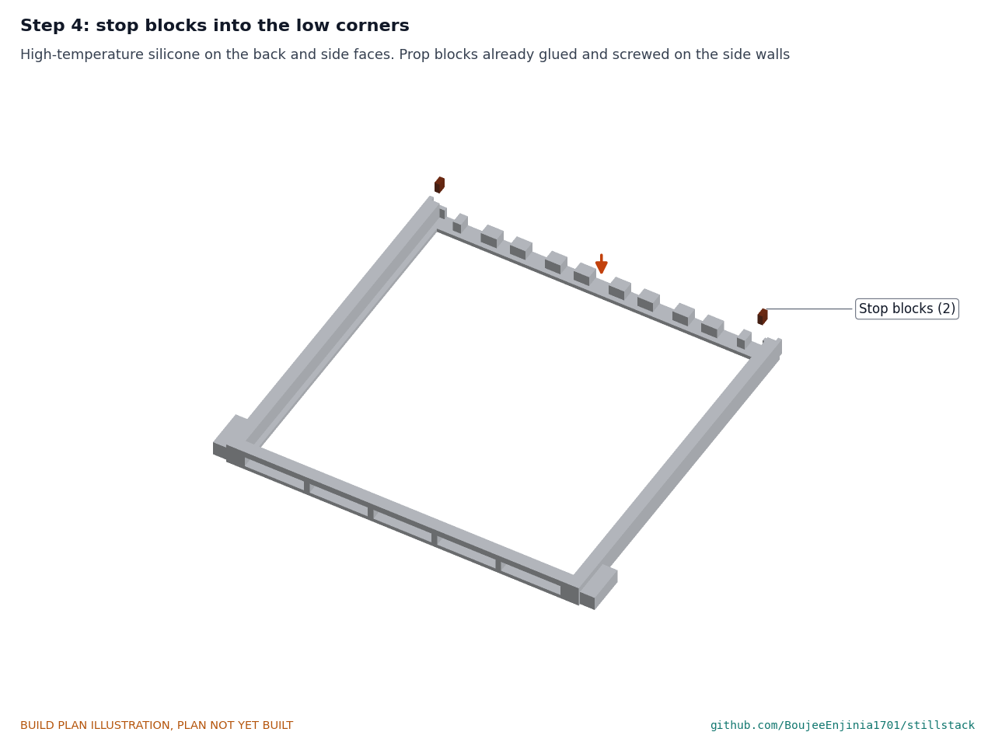
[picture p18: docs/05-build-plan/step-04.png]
Figure 12. Step 4 picture: stop blocks into the corners


*Figure 12. Where the stop blocks go.*

**Check before moving on.** Both front faces are square to the side walls and 996 mm from the high liner face.

### 3.7 Bottom plate and fins

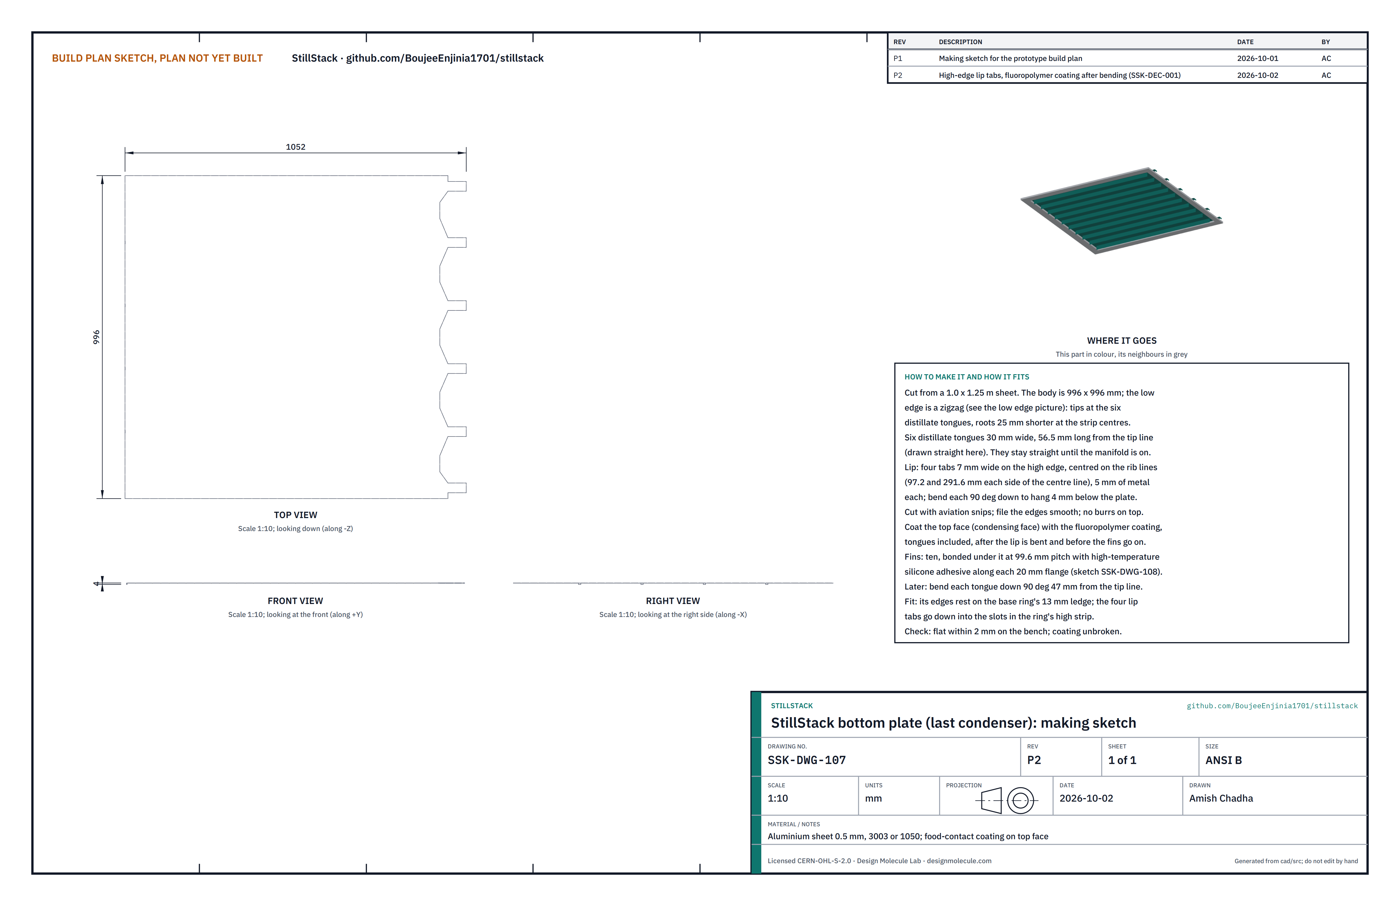
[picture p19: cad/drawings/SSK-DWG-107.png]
Figure 13. Making sketch of the bottom plate


*Figure 13. Bottom plate making sketch (SSK-DWG-107), tongues drawn straight.*

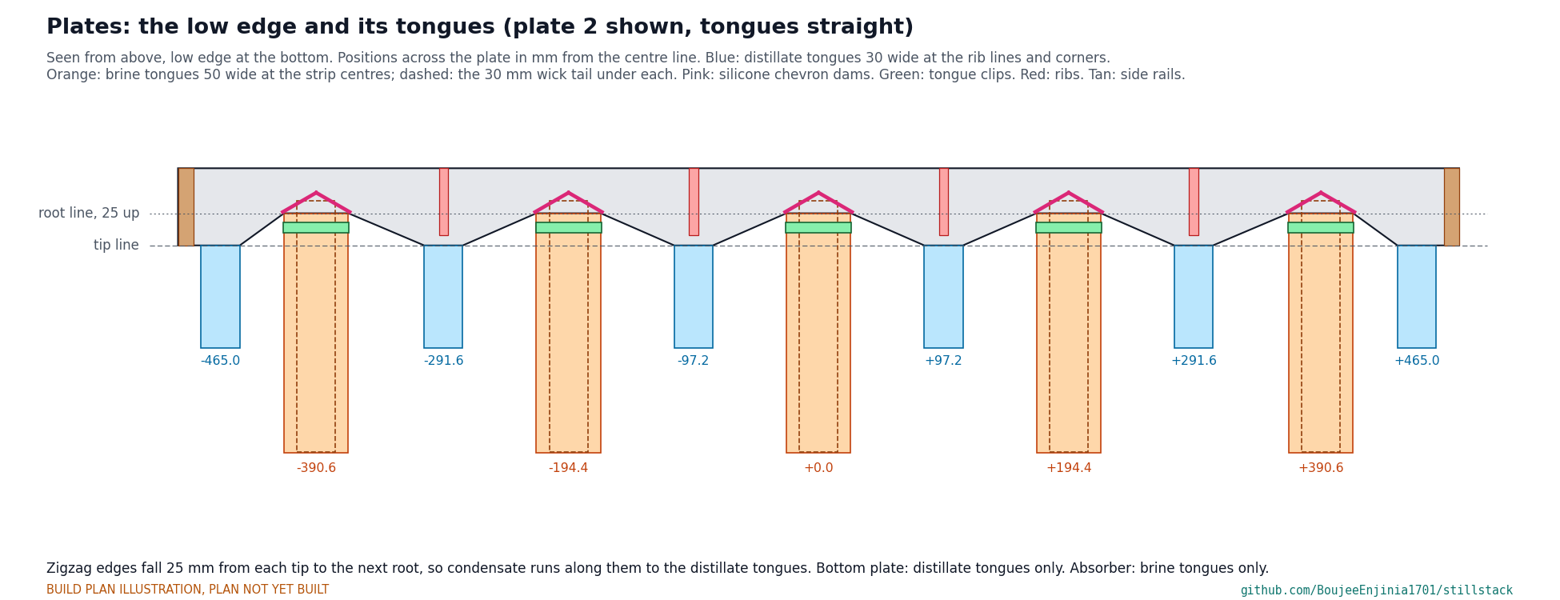
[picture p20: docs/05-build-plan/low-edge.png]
Figure 14. The plates' low edge and tongues


*Figure 14. The zigzag low edge and the tongue positions, shared by all five plates.*

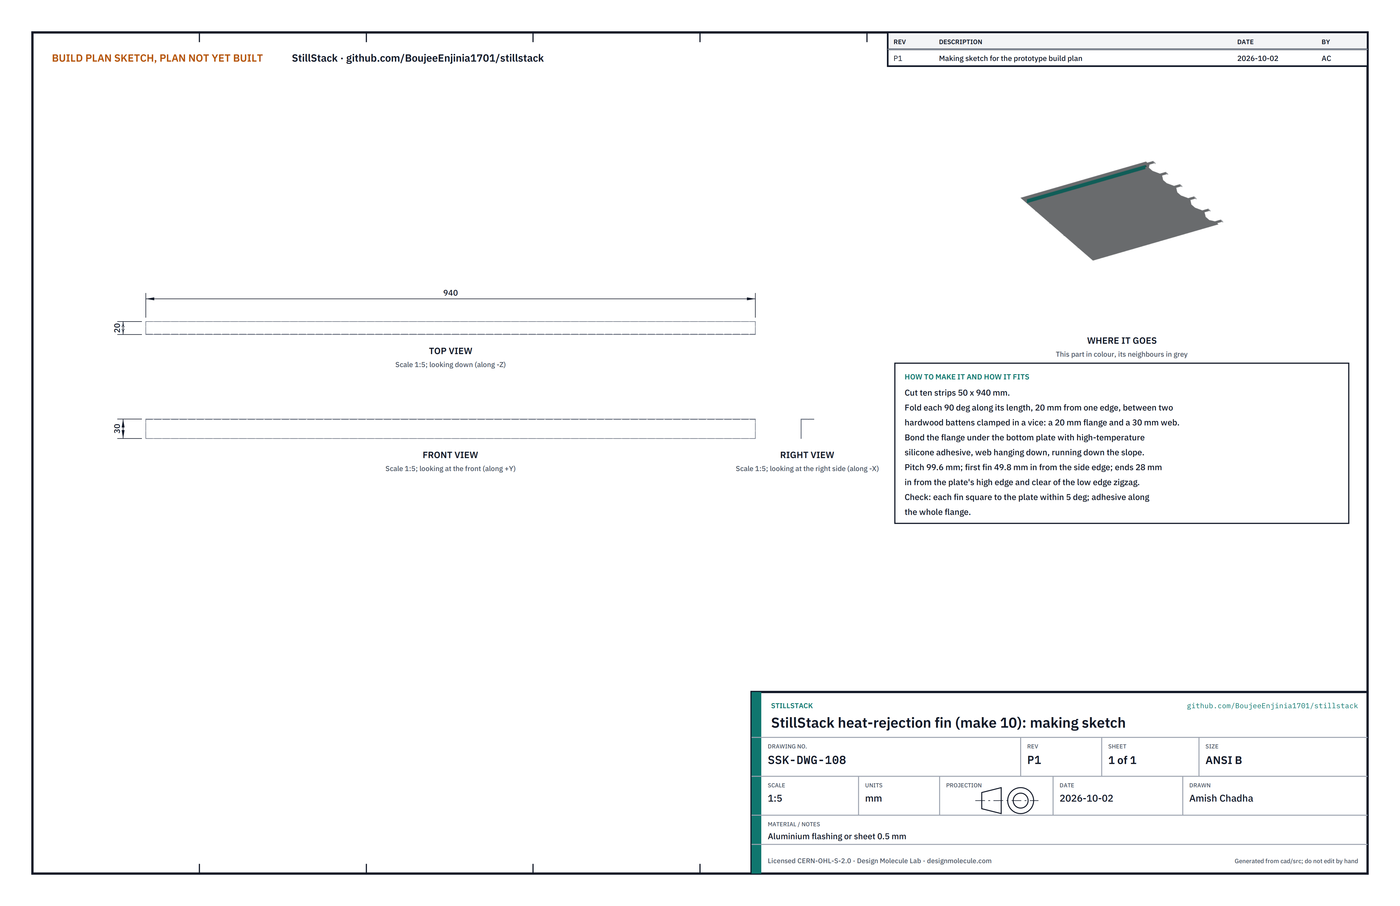
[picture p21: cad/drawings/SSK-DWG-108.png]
Figure 15. Making sketch of the fin


*Figure 15. Fin making sketch (SSK-DWG-108).*

**What it is and what it is made from.** The last condenser: stage 4 condenses on its top face, and the fins underneath shed the remaining heat to the air. Aluminium sheet 0.5 mm, 3003 or 1050, with a fluoropolymer (PTFE or PFA type) cookware coating on its top face, certified for drinking-water contact and rated to 150 °C dry; fins of 0.5 mm aluminium flashing.

**How to make it.**

1. From a 1.0 x 1.25 m sheet (the blank, tongues and lip included, is 1,224 mm long, so it fits), cut a body 996 x 996 mm whose low edge is the zigzag of Figure 14: tips at the six distillate tongue lines, falling 25 mm to a flat root at each strip centre.
2. Leave six distillate tongues 30 mm wide and 56.5 mm long beyond the tip line, straight for now. Mark a bend line 47 mm from the tip line on each.
3. Lip: on the high edge leave four tabs 7 mm wide, centred 97.2 and 291.6 mm each side of the centre line (the rib lines), each 5 mm long beyond the edge. Bend each 90° down over a steel bar so it hangs 4 mm below the plate.
4. File every edge smooth and free of burrs.
5. Coat the top face, tongues included, with the coating, after the tabs are bent.
6. Fins: cut ten strips 50 x 940 mm and fold each 90° along its length 20 mm from one edge, between two hardwood battens clamped in a vice.
7. Bond each fin's 20 mm flange under the plate with high-temperature silicone adhesive, web hanging down and running down the slope, at 99.6 mm pitch with the first 49.8 mm in from a side edge and the ends 28 mm in from the high edge.

**How it fits the parts next to it.**

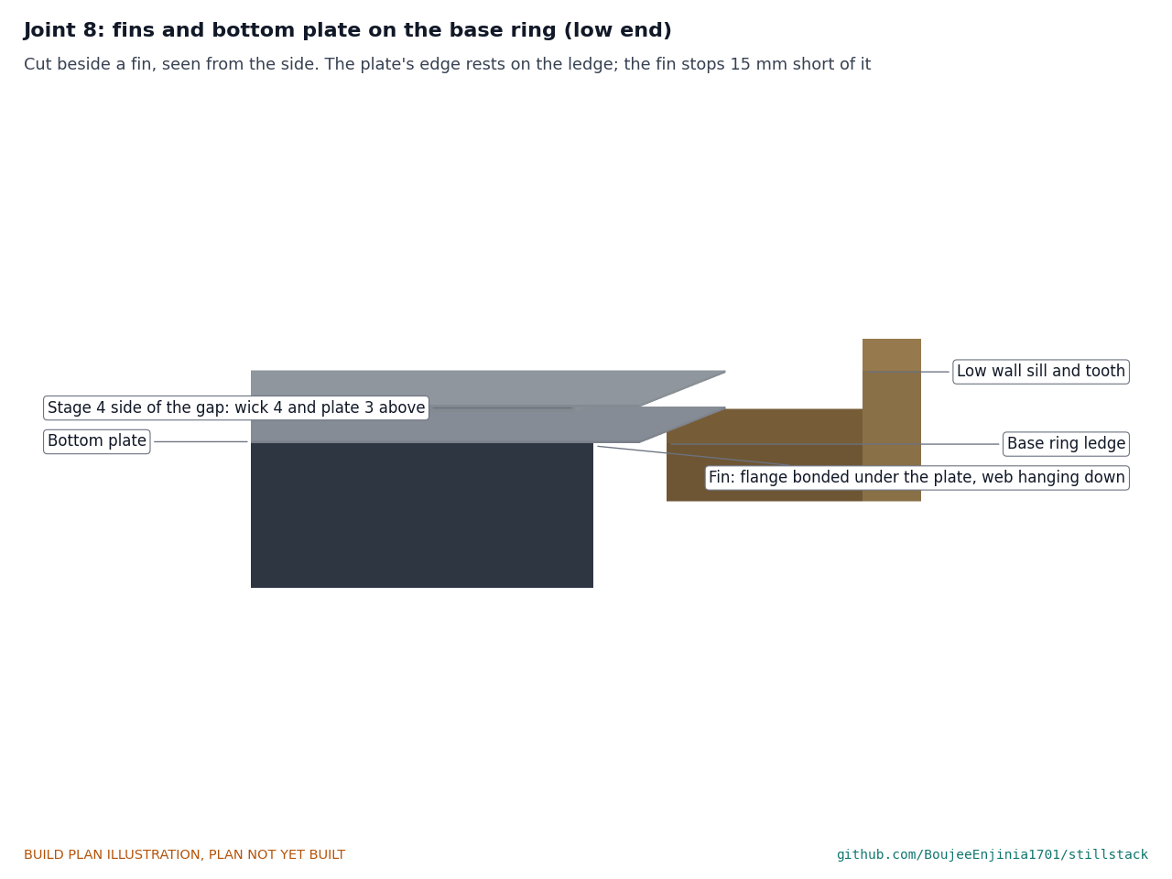
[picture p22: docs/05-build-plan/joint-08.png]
Figure 16. Joint 8: fins and bottom plate on the base ring


*Figure 16. Cut beside a fin: the plate's edge rests on the ledge; the fin stops 15 mm short of it.*

The plate's four edges rest on the base ring's ledge; its corners touch the stop blocks; its tongues lie on the low wall's sill in the notches.

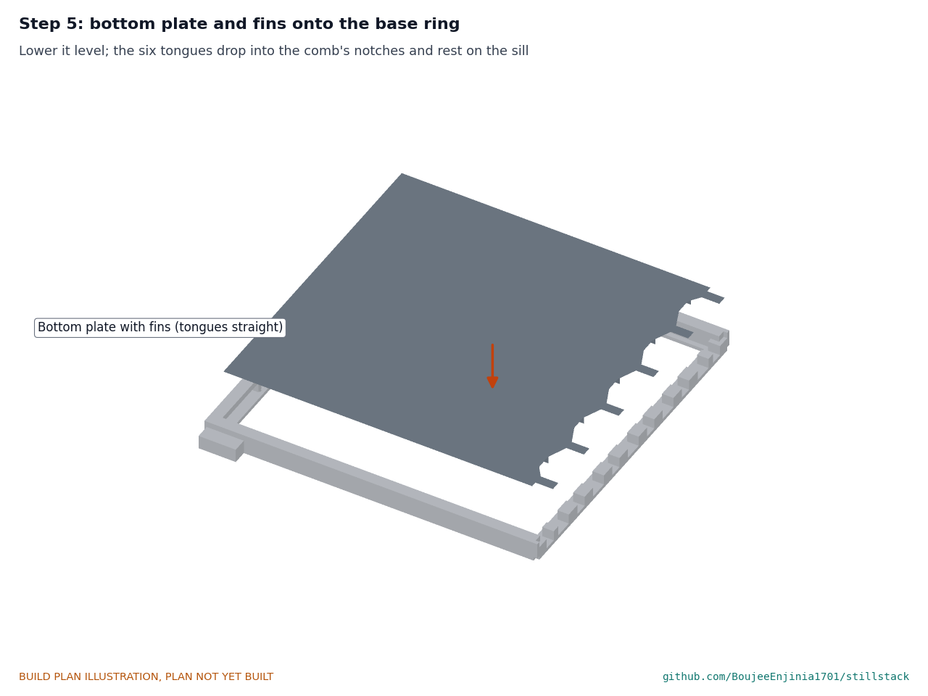
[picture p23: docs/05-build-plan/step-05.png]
Figure 17. Step 5 picture: bottom plate and fins onto the base ring


*Figure 17. The bottom plate is lowered level onto the ledge.*

**Check before moving on.** The plate is flat within 2 mm on the bench; the coating is unbroken; every fin is square to the plate within 5° and bonded along its whole flange.

### 3.8 Side rails (make 8)

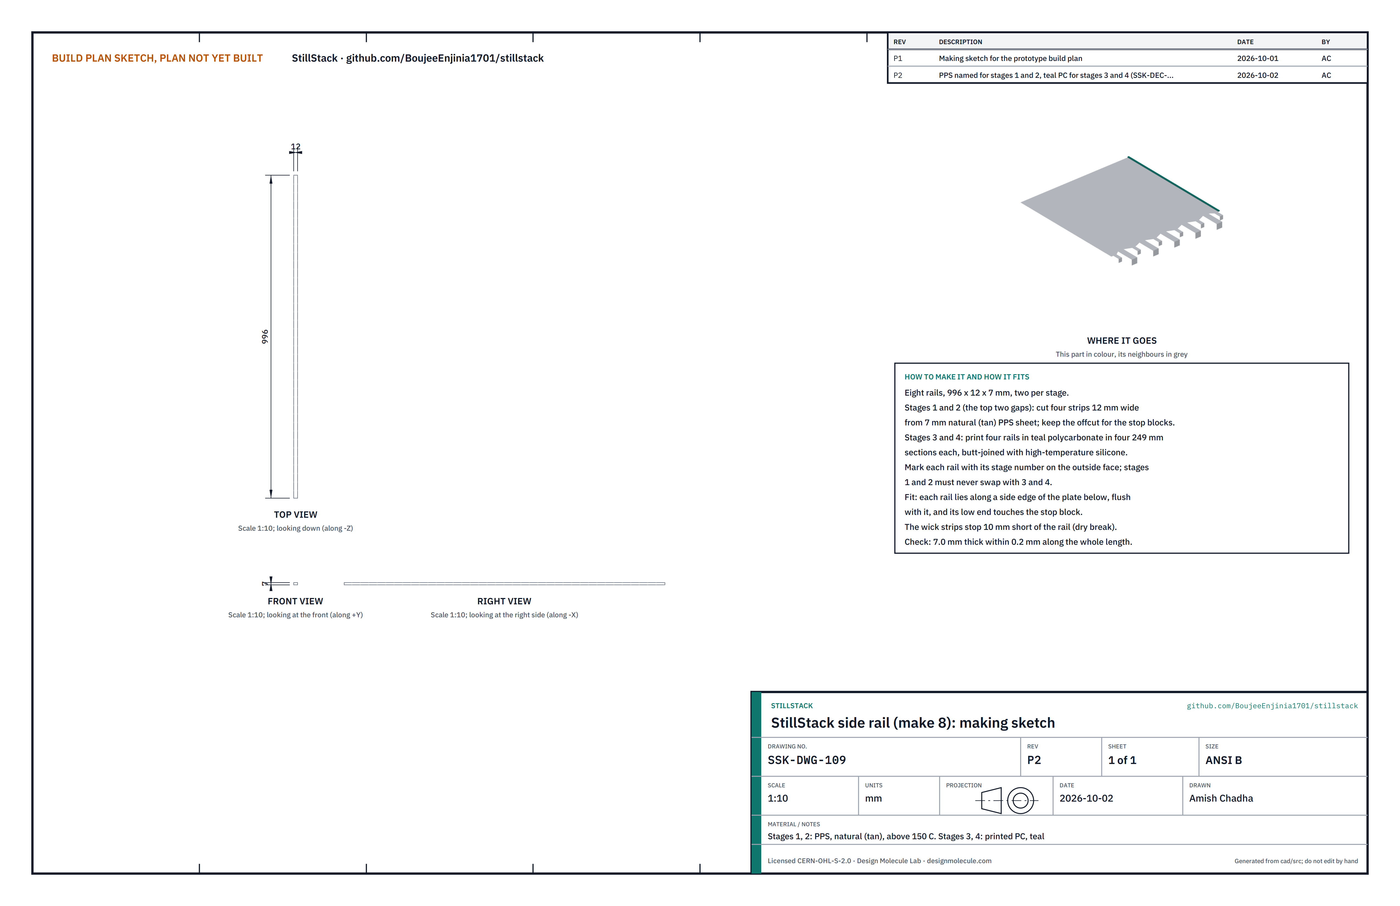
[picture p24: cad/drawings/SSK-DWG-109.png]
Figure 18. Making sketch of the side rail


*Figure 18. Side rail making sketch (SSK-DWG-109).*

**What it is and what it is made from.** Two rails per gap, along the side edges, that hold the plates 7 mm apart (6 mm gap plus the 1 mm wick). Stages 1 and 2 (the top two gaps): natural (tan) PPS rated above 150 °C (decided 2026-10-02). Stages 3 and 4: printed polycarbonate in teal, so the two kinds never swap.

**How to make it.**

1. Stages 1 and 2: cut four strips 996 x 12 mm from 7 mm PPS sheet; keep the offcut for the stop blocks.
2. Stages 3 and 4: print four rails 996 x 12 x 7 mm in teal polycarbonate, each in four 249 mm sections, and butt-join the sections with high-temperature silicone.
3. Mark each rail with its stage number on the outside face.

**How it fits the parts next to it.**

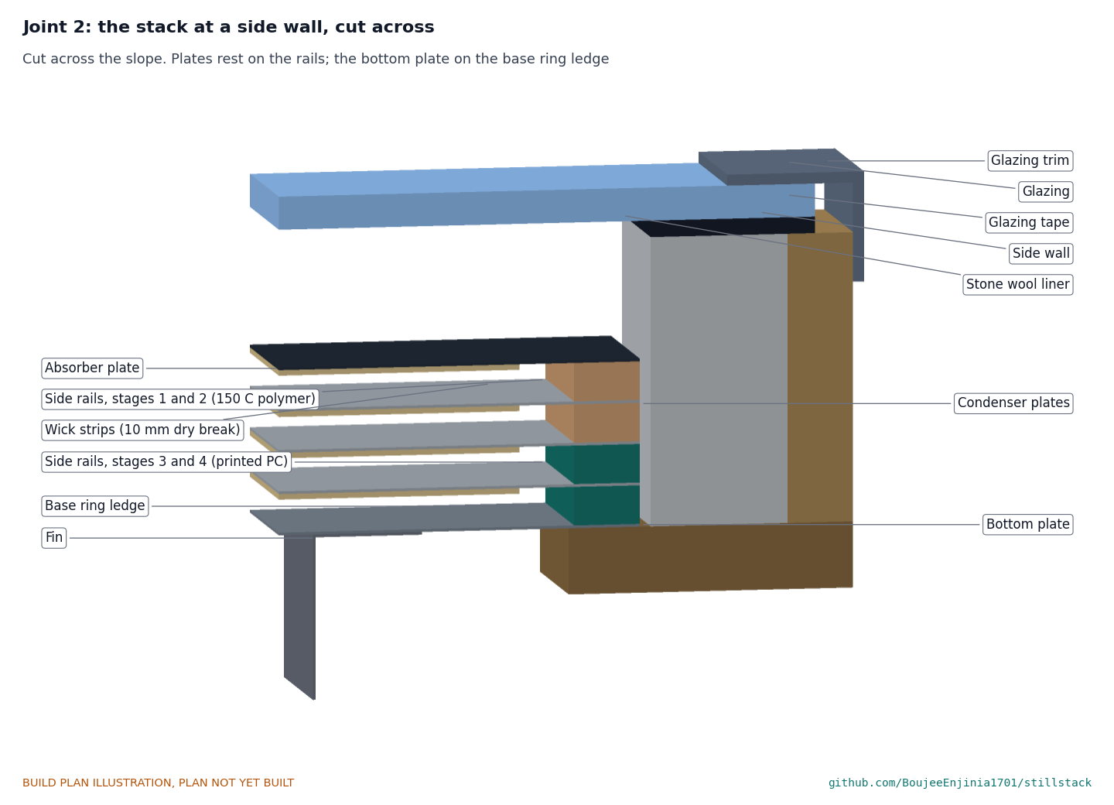
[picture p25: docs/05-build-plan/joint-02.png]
Figure 19. Joint 2: the stack at a side wall, cut across


*Figure 19. Cut across the slope: each rail lies along a side edge of the plate below and carries the plate above; the wicks stop 10 mm short of the rails.*

Each rail lies flush with a side edge of the plate below, its low end touching the stop block. The plate above rests on it. The wick strips stop 10 mm short of the rails, a dry break that keeps brine from creeping along the rail.

**Check before moving on.** Each rail is 7.0 mm thick within 0.2 mm along its whole length; stages 1 and 2 are never swapped with 3 and 4.

### 3.9 Spacer ribs and chevron dams

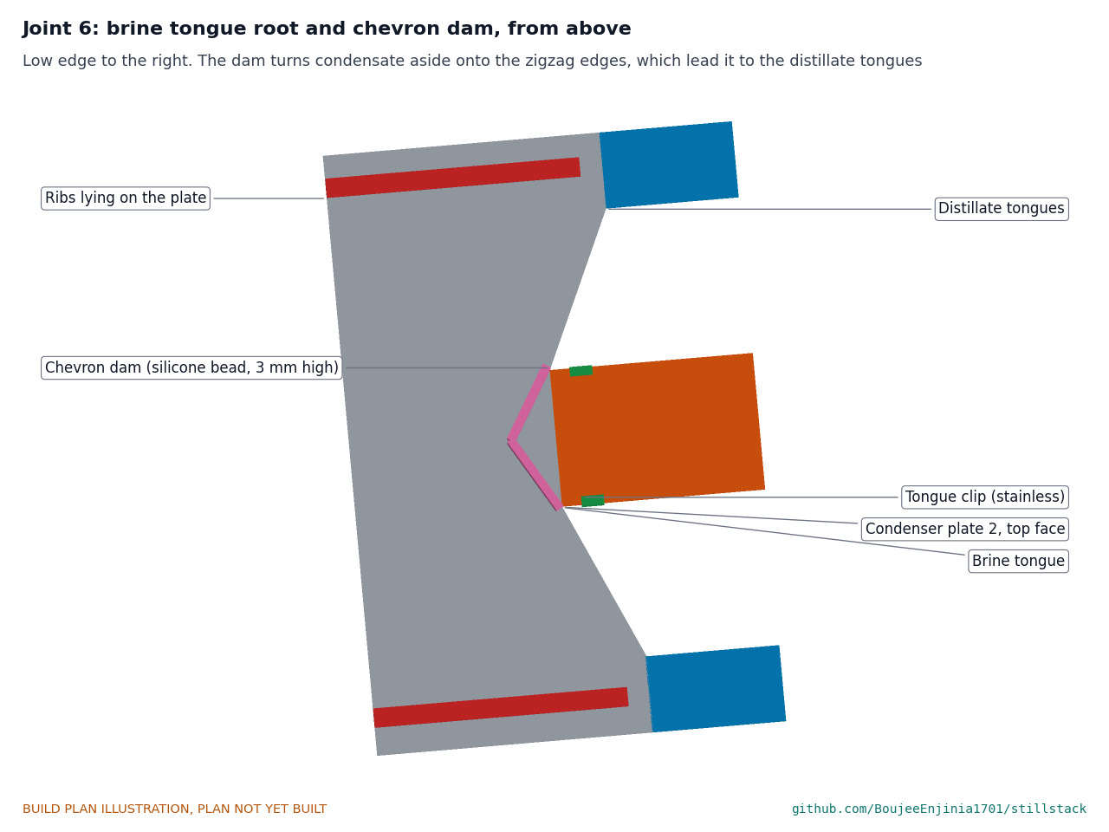
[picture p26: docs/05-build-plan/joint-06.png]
Figure 20. Joint 6: brine tongue root and chevron dam, from above


*Figure 20. A rib on a rib line, and the silicone chevron at a brine tongue root.*

**What they are and what they are made from.** Ribs: four 7 mm food-grade silicone cords per gap, running down the slope on the rib lines, which stop the 0.5 mm plates sagging between the rails. Dams: a bead of food-grade silicone on the top face of each condenser plate at each brine tongue root.

**How to make them.**

1. Cut sixteen lengths of cord 988 mm long.
2. Dams: after each condenser plate is in place (steps 6 to 8), run a bead 3 mm high in a V on its top face at each brine tongue root: the point 16 mm up the slope from the root, the two legs ending at the root's corners (Figures 14 and 20).

**How they fit the parts next to them.** The ribs lie on the rib lines (97.2 and 291.6 mm each side of the centre line), from the high edge to 8 mm short of the tongue tips, between the wick strips' dry breaks. The dams turn condensate running down the plate aside onto the zigzag edges, which lead it to the distillate tongues.

**Check before moving on.** Each rib lies straight on its line; each dam is continuous and its legs meet the root corners.

### 3.10 Condenser plates 1 to 3

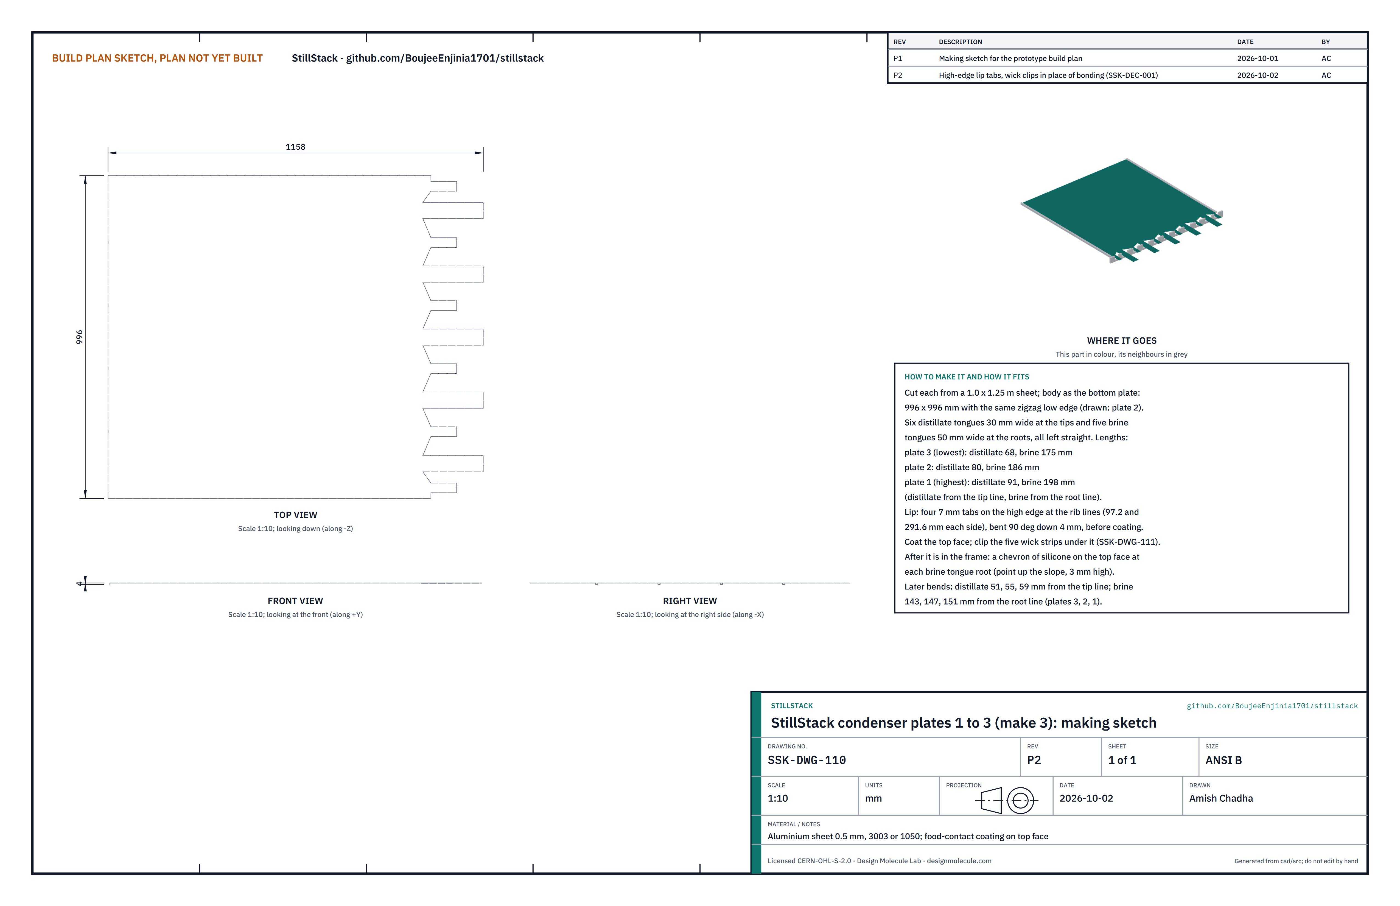
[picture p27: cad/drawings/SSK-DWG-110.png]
Figure 21. Making sketch of the condenser plate


*Figure 21. Condenser plate making sketch (SSK-DWG-110), plate 2 shown with its tongues straight.*

**What they are and what they are made from.** The three plates between the absorber and the bottom plate. Each condenses the stage above on its top face and carries the wick of the stage below on its underside. Aluminium sheet 0.5 mm with the fluoropolymer coating on the top face (as for the bottom plate).

**How to make them.**

1. From a 1.0 x 1.25 m sheet each, cut the same 996 x 996 mm body, lip tabs and zigzag low edge as the bottom plate (Figure 14).
2. Leave six distillate tongues 30 mm wide at the tips and five brine tongues 50 mm wide at the roots, all straight. Lengths, distillate from the tip line and brine from the root line: plate 3 (lowest) 68 and 175 mm; plate 2, 80 and 187 mm; plate 1 (highest), 91 and 198 mm.
3. Mark the bend lines: distillate 51, 55 and 59 mm from the tip line, brine 143, 147 and 151 mm from the root line, for plates 3, 2 and 1.
4. Lip: on the high edge leave four tabs 7 mm wide at the rib lines (97.2 and 291.6 mm each side of the centre line) and bend each 90° down so it hangs 4 mm below the plate. The tabs stand clear of the wick strips and of the rib ends.
5. Deburr, coat the top face after the tabs are bent, and clip the five wick strips of the stage below under it (section 3.11).

**How they fit the parts next to them.**

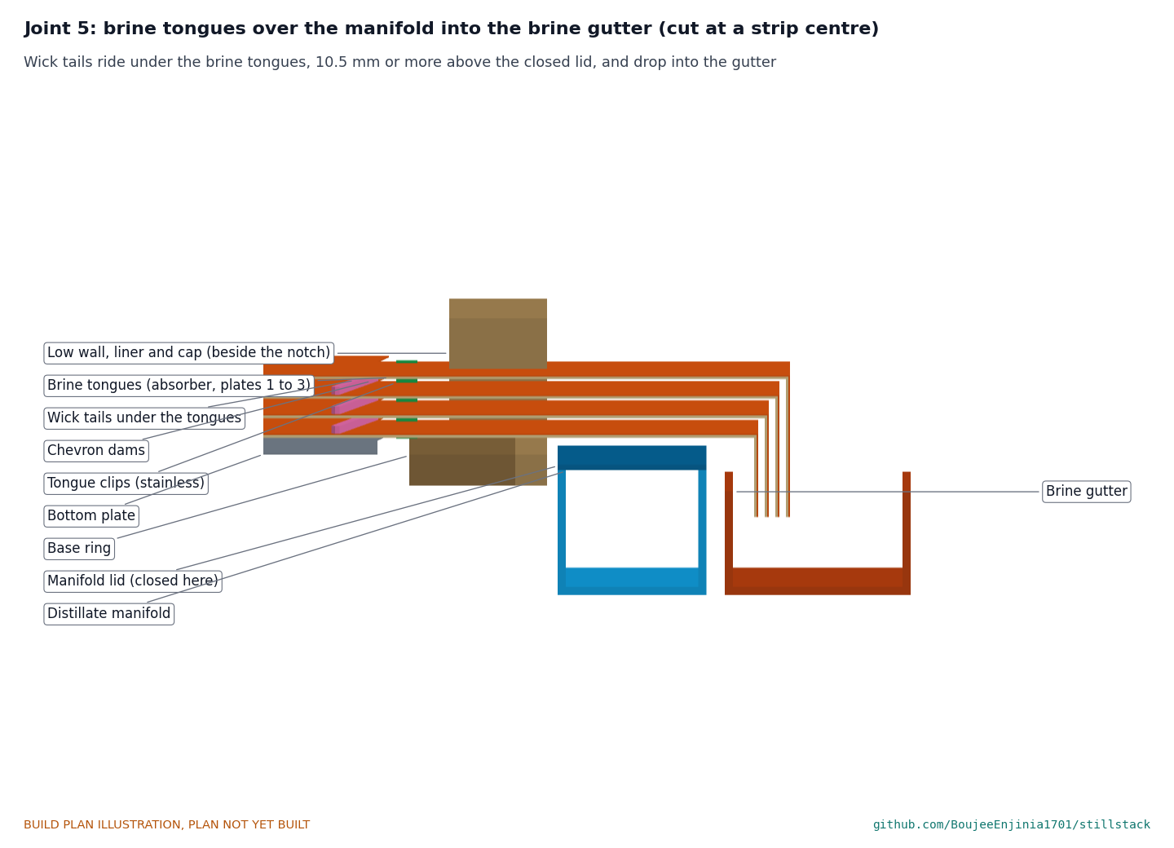
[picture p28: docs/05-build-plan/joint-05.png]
Figure 22. Joint 5: brine tongues over the manifold into the brine gutter


*Figure 22. Cut at a strip centre: each brine tongue carries its wick tail over the closed manifold lid and turns down into the brine gutter.*

Each plate rests on the rails and ribs of the gap below, its corners against the stop blocks and its tongues in the low wall's notches. Once the manifold and gutter are fitted, the distillate tongues are bent down into the manifold and the brine tongues down into the gutter, each 4 mm outside the one below (steps 15 and 17). The lowest brine tongue's wick tail passes 10.5 mm above the lid; the nearest distillate tongue is 44 mm away to the side.

**Check before moving on.** Each plate is flat within 2 mm, its coating unbroken, its tongues the right length for its level.

### 3.11 Wick strips (make 20: five per stage)

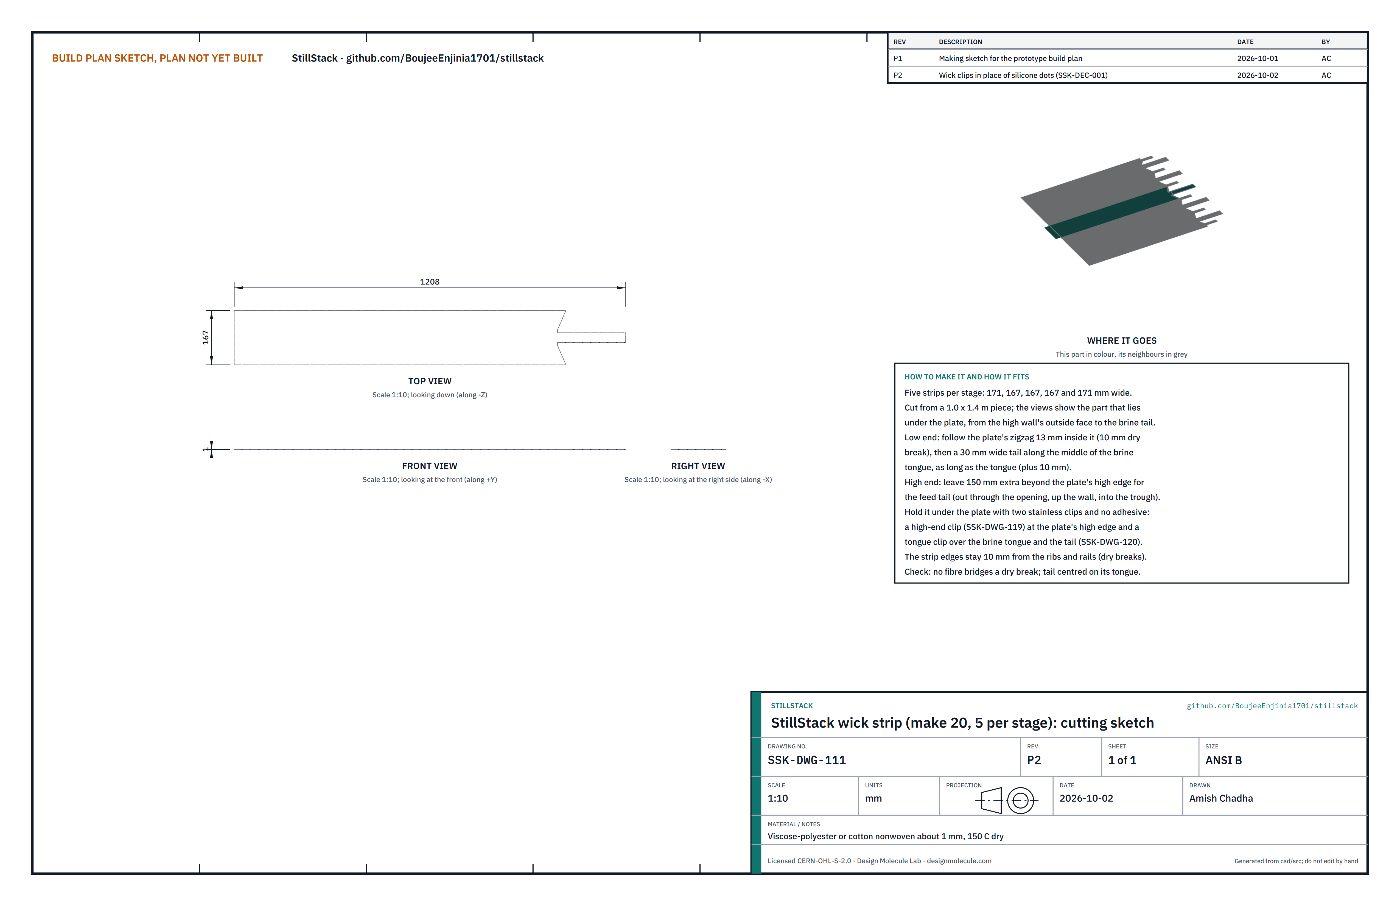
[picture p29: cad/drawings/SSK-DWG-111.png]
Figure 23. Cutting sketch of the wick strip


*Figure 23. Wick strip cutting sketch (SSK-DWG-111): the part under the plate, with the brine tail.*

**What they are and what they are made from.** The wet cloth that evaporates water in each stage, fed from the trough at the high end, with its excess leaving as brine at the low end. Nonwoven about 1 mm thick that tolerates 150 °C dry.

**How to make them.**

1. For each stage cut a 1.0 x 1.4 m piece into five strips: 171, 167, 167, 167 and 171 mm wide.
2. Low end: cut each strip to follow its plate's zigzag edge 13 mm inside it (a 10 mm dry break), then leave a 30 mm wide tail along the middle of the brine tongue, as long as the tongue plus 10 mm.
3. High end: leave 150 mm beyond the plate's high edge for the feed tail.
4. Lay the plate face down on a clean table. Slide a high-end clip (Figure 24) onto each strip so its bar lies under the wick and its ears hook round the plate edge in the dry breaks beside the strip, then slide a tongue clip (Figure 25) onto the brine tongue so it holds the tail centred under the tongue. Use no adhesive, so the wicks lift out for rinsing.

**How they fit the parts next to them.** Each strip lies between a rail and a rib, or between two ribs, with 10 mm of dry plate on each side; the clip ears sit in those dry breaks, beside the lip tabs (Figure 26). The feed tail leaves through the high wall opening for its strip (Figure 4); the brine tail rides under its brine tongue (Figure 22).

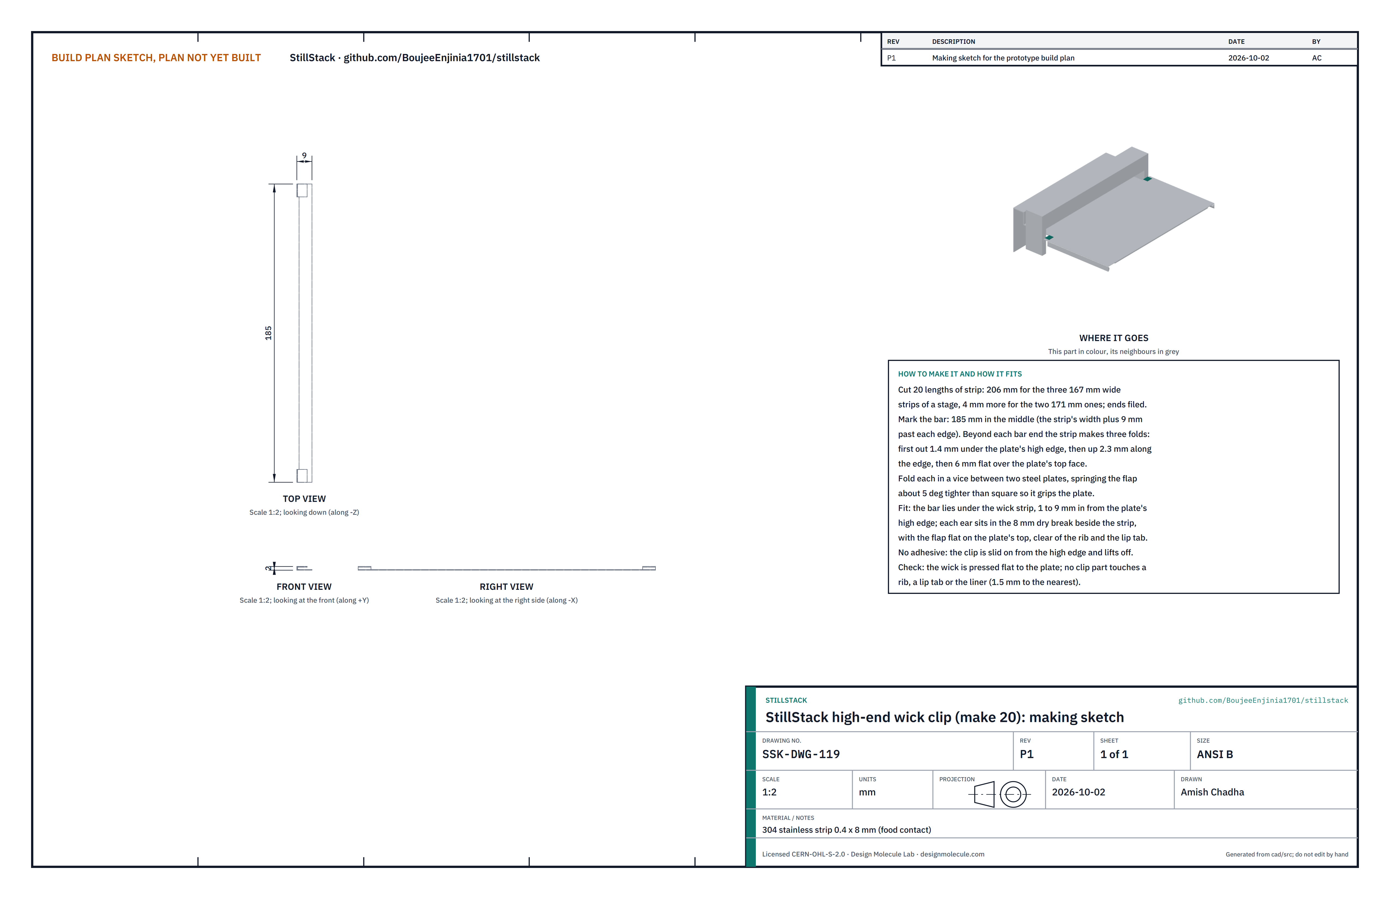
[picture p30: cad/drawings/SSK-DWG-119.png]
Figure 24. Making sketch of the high-end wick clip


*Figure 24. High-end wick clip making sketch (SSK-DWG-119): a 0.4 x 8 mm stainless strip, shown for the centre strip of a stage.*

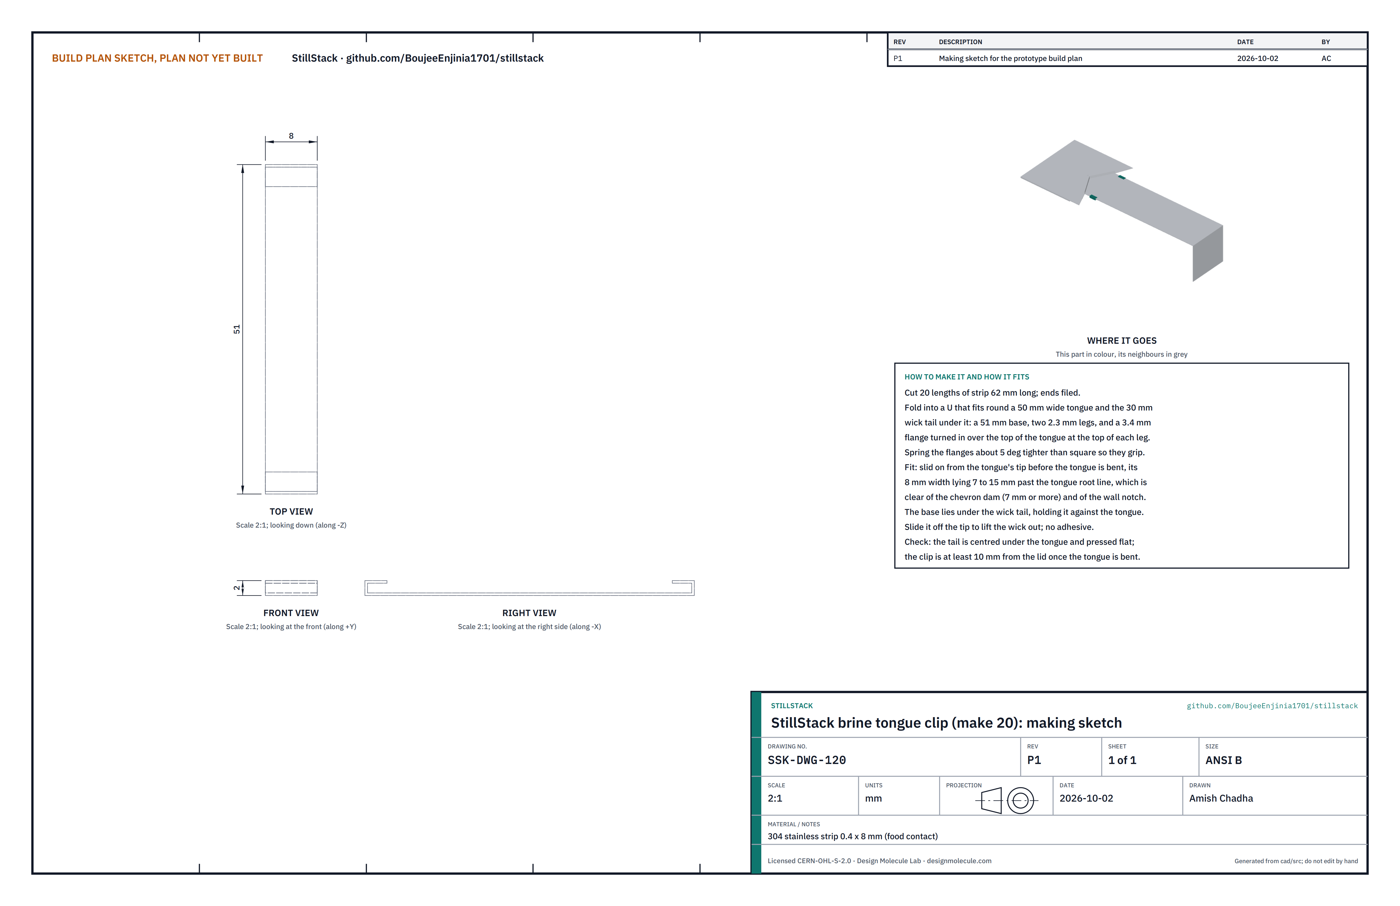
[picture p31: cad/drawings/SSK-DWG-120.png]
Figure 25. Making sketch of the brine tongue clip


*Figure 25. Brine tongue clip making sketch (SSK-DWG-120).*

**The two clips.** Both are folded by hand from 0.4 x 8 mm 304 stainless strip, 20 of each (40 in all). The high-end clip is 206 mm long for a 167 mm strip: a 185 mm bar under the wick, and at each end three folds that carry an ear out under the plate's high edge, up along it and 6 mm flat over its top face, in the dry break beside the strip. The tongue clip is 62 mm long: a 51 mm base under the wick tail, two 2.3 mm legs up the sides of the brine tongue and a 3.4 mm flange turned in over the tongue's top face. Spring the flaps about 5° tighter than square so they grip. Neither clip touches a rib, a lip tab, the liner or the lid (the nearest is 1.5 mm).

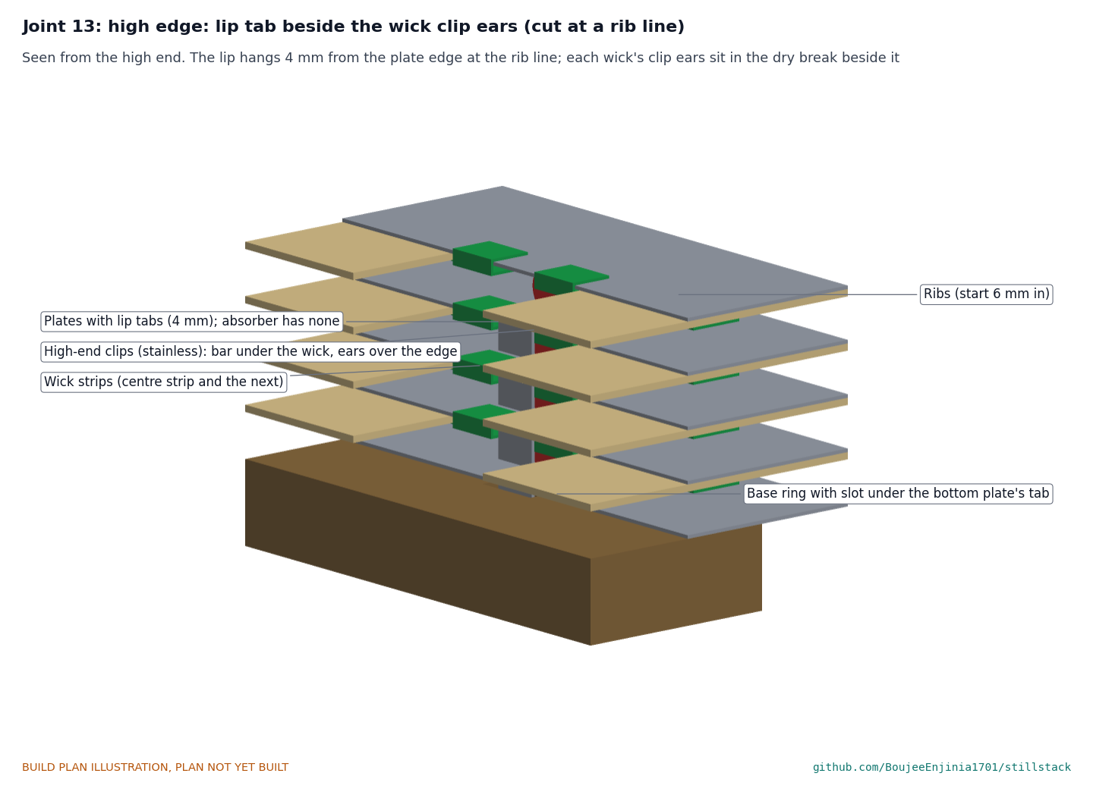
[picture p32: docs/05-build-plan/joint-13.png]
Figure 26. Joint 13: the high edge with its lip tab and wick clip ears


*Figure 26. Seen from the high end, cut at a rib line: the lip hangs 4 mm from the plate edge at the rib line, and each wick's clip ears sit in the dry break beside the strip.*

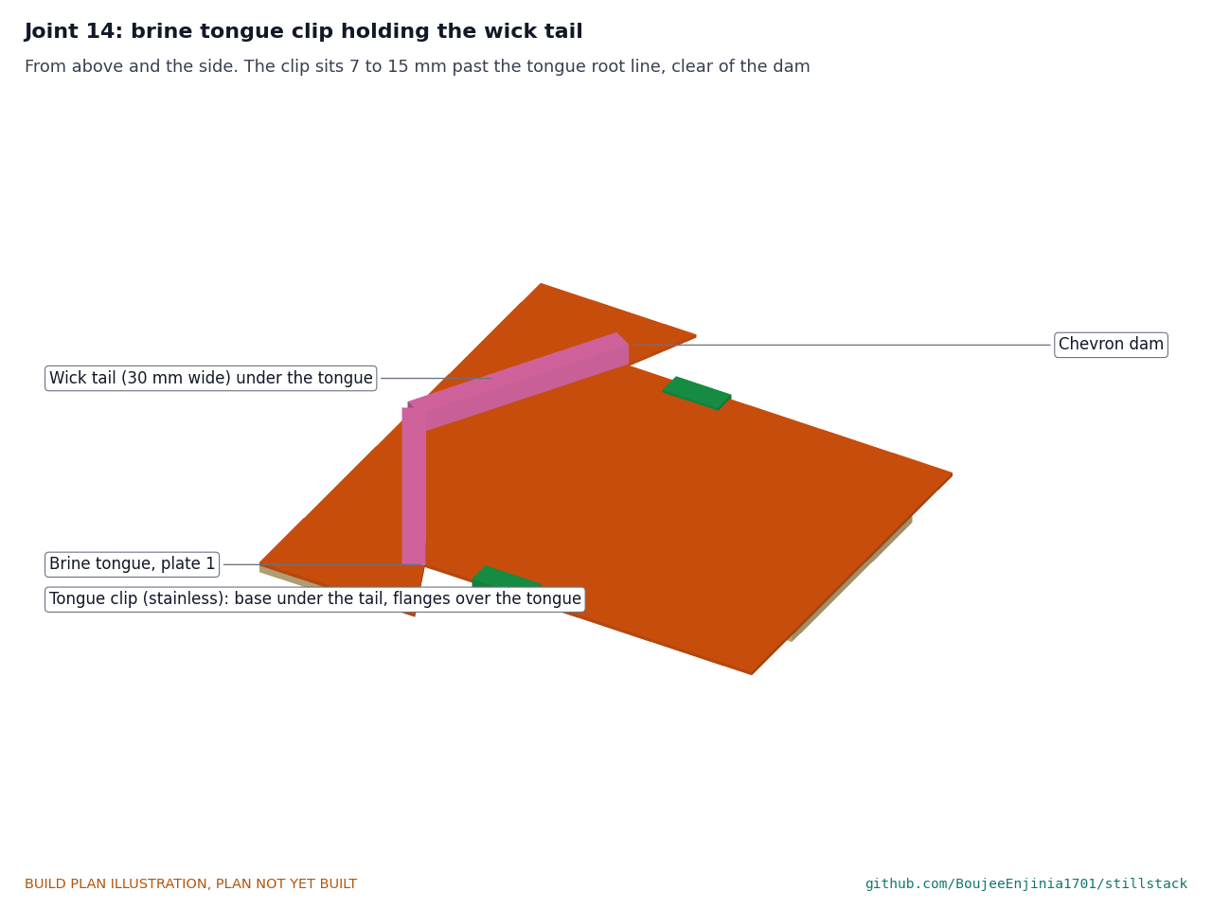
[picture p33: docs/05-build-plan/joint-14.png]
Figure 27. Joint 14: the brine tongue clip


*Figure 27. The tongue clip holds the 30 mm wick tail under the 50 mm brine tongue, 7 to 15 mm past the root line and clear of the chevron dam.*

**Check before moving on.** No fibre bridges a dry break; each tail is centred on its tongue.

### 3.12 Absorber plate

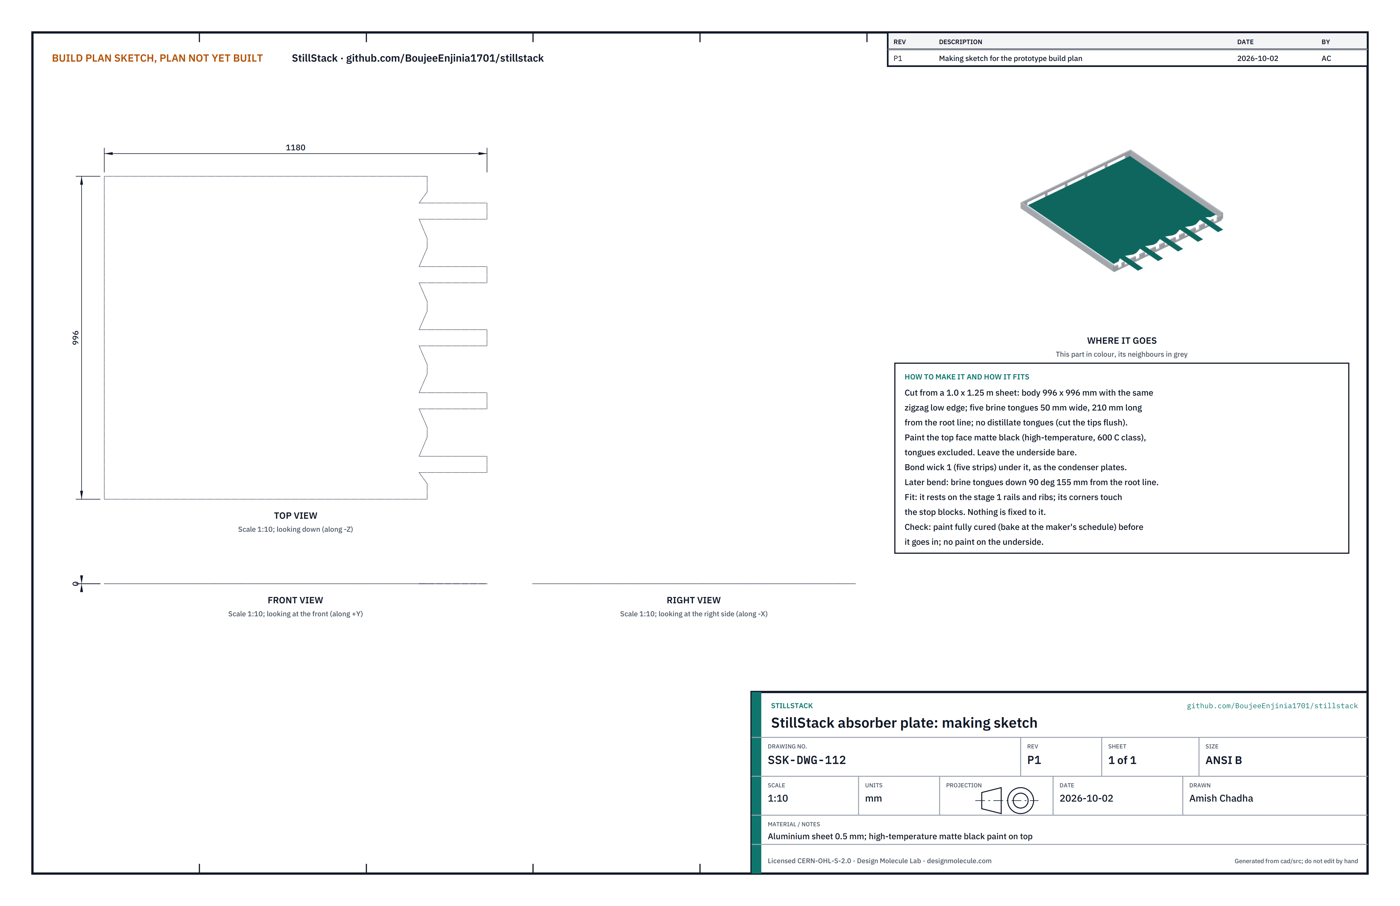
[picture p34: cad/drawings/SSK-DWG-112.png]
Figure 28. Making sketch of the absorber plate


*Figure 28. Absorber plate making sketch (SSK-DWG-112).*

**What it is and what it is made from.** The top plate that absorbs the sunlight; stage 1's wick is bonded under it. Aluminium sheet 0.5 mm with high-temperature matte black paint on top.

**How to make it.**

1. Cut the same body and zigzag edge as the other plates, with five brine tongues 50 mm wide and 210 mm long from the root line and no distillate tongues (cut the tips flush). Mark the brine bend line 155 mm from the root line.
2. Paint the top face matte black with a high-temperature paint (600 °C class), tongues excluded, and cure it to the maker's schedule. Leave the underside bare.
3. Bond the five strips of wick 1 under it.

**How it fits the parts next to it.** It rests on the stage 1 rails and ribs, its corners against the stop blocks. Nothing is fixed to it.

**Check before moving on.** The paint is fully cured; there is no paint on the underside.

### 3.13 Glazing trim (make 4)

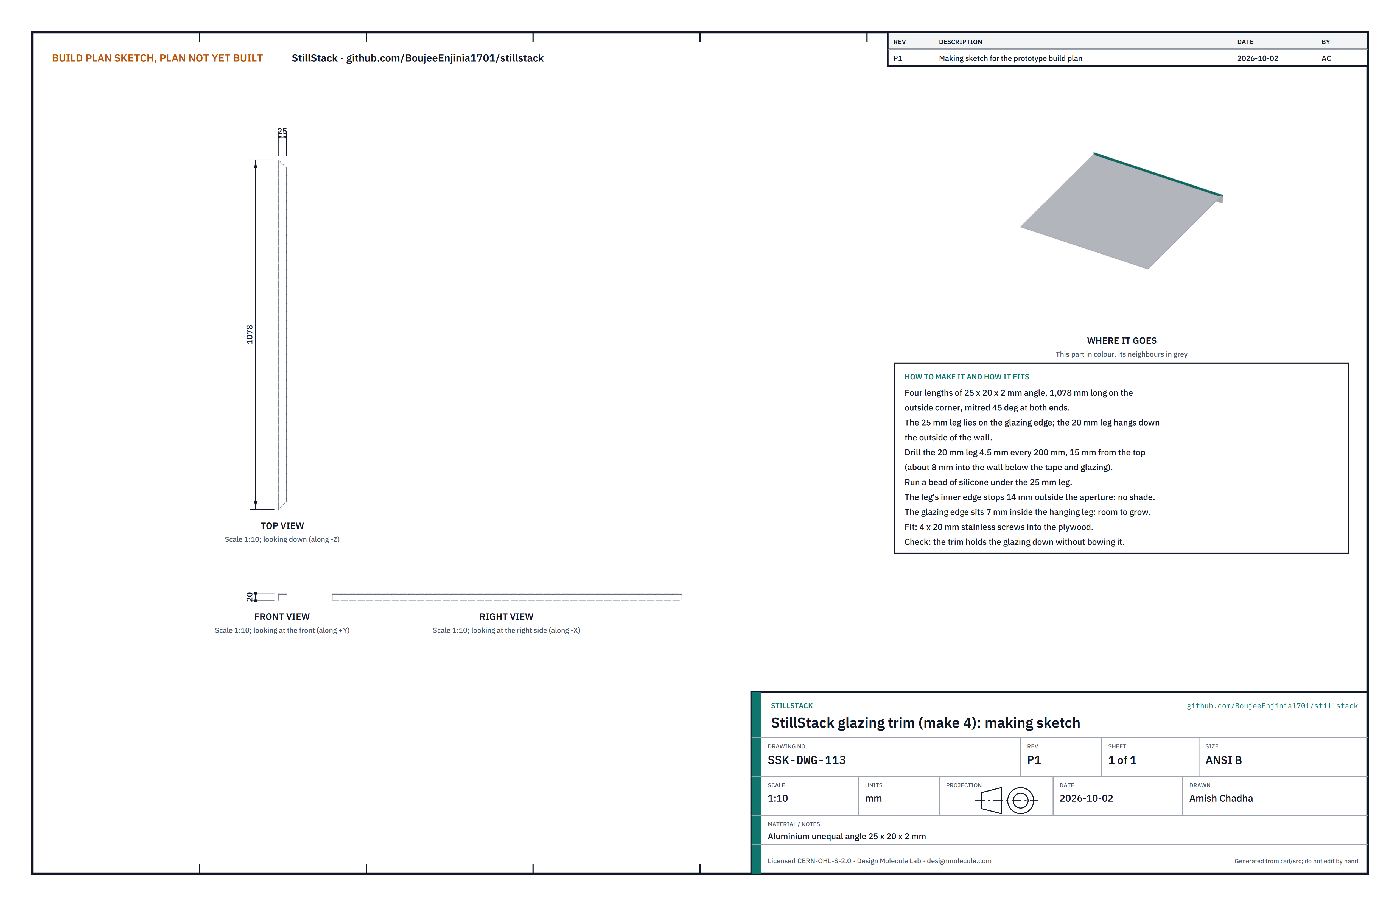
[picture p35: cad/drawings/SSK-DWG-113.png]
Figure 29. Making sketch of the glazing trim


*Figure 29. Glazing trim making sketch (SSK-DWG-113).*

**What it is and what it is made from.** The frame that holds the glazing down on the walls. Aluminium unequal angle 25 x 20 x 2 mm.

**How to make it.**

1. Cut four lengths 1,078 mm on the outside corner, mitred 45° at both ends.
2. Drill the 20 mm leg 4.5 mm every 200 mm, 15 mm from its top edge.

**How it fits the parts next to it.**

Figure 30. The trim, glazing and tape at the top of a side wall

*Figure 30. The 25 mm leg lies on the glazing edge over a bead of silicone; the 20 mm leg hangs down the outside of the wall (detail of Figure 19).*

The glazing sits on 3 mm foam tape on the wall tops, its edge 7 mm inside the trim's hanging leg so it can grow when hot. The trim's top leg stops 14 mm outside the aperture, so it casts no shade. Four 4 x 20 mm stainless screws per length go through the hanging leg into the plywood.

**Check before moving on.** The trim holds the glazing down without bowing it.

### 3.14 Distillate manifold lid

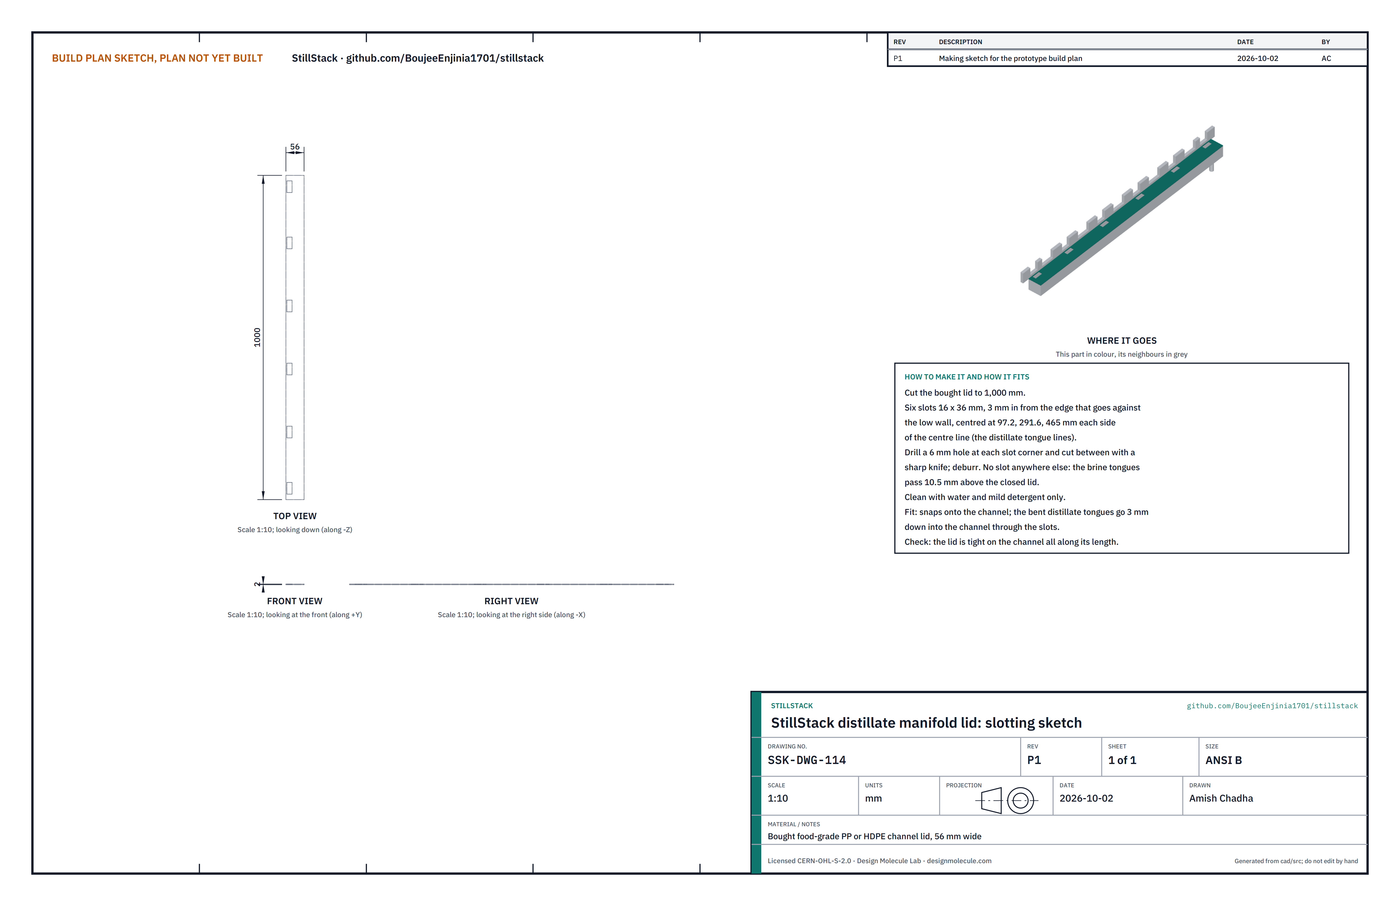
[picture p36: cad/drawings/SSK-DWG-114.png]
Figure 31. Slotting sketch of the manifold lid


*Figure 31. Manifold lid slotting sketch (SSK-DWG-114).*

**What it is and what it is made from.** The lid of the bought food-grade channel that collects the distillate. Six slots let the distillate tongues in; everywhere else the lid is closed, so brine dripping above it cannot reach the distillate.

**How to make it.**

1. Cut the channel and its lid to 1,000 mm.
2. Cut six slots 16 x 36 mm in the lid, 3 mm in from the edge that goes against the low wall, centred 97.2, 291.6 and 465 mm each side of the centre line. Drill a 6 mm hole at each corner and cut between them with a sharp knife.
3. Clean with water and mild detergent only.

**How it fits the parts next to it.**

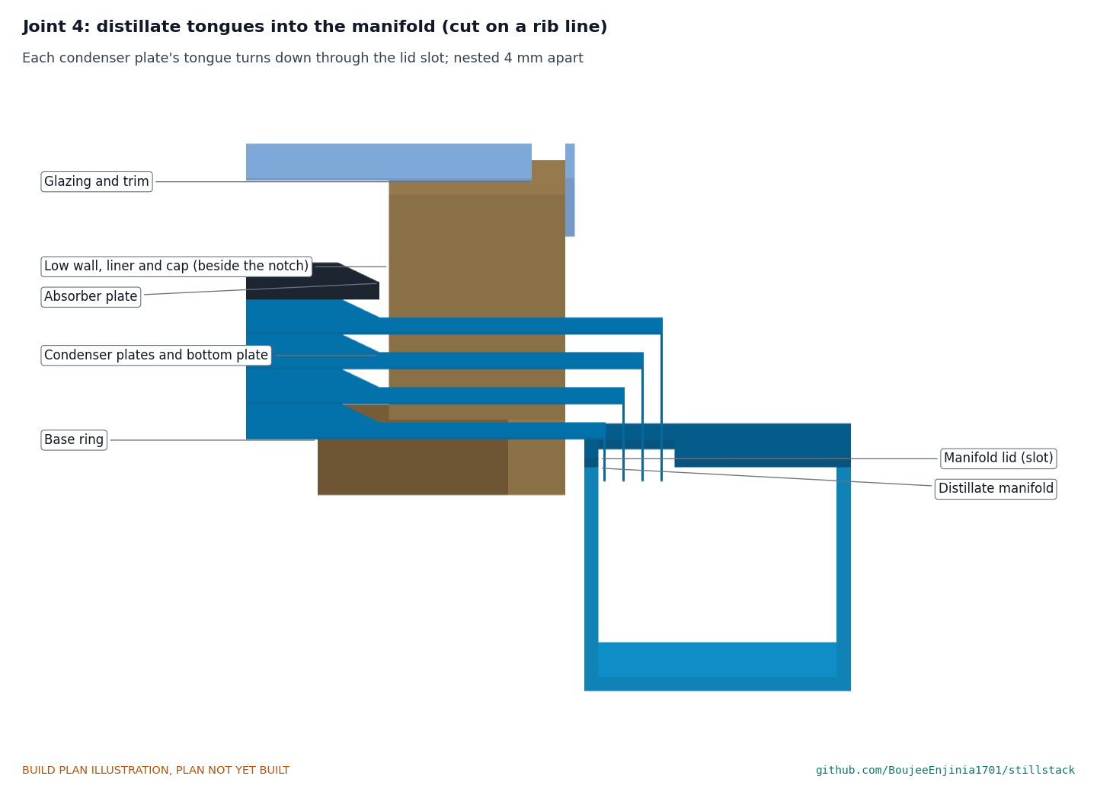
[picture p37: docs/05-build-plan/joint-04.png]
Figure 32. Joint 4: distillate tongues into the manifold


*Figure 32. Cut on a rib line: each condenser plate's tongue turns down through the slot, 4 mm outside the one below, and ends 3 mm inside the channel.*

**Check before moving on.** The lid is tight on the channel all along its length; the slots line up with the notches in the low wall.

### 3.15 Outlet brackets (make 2)

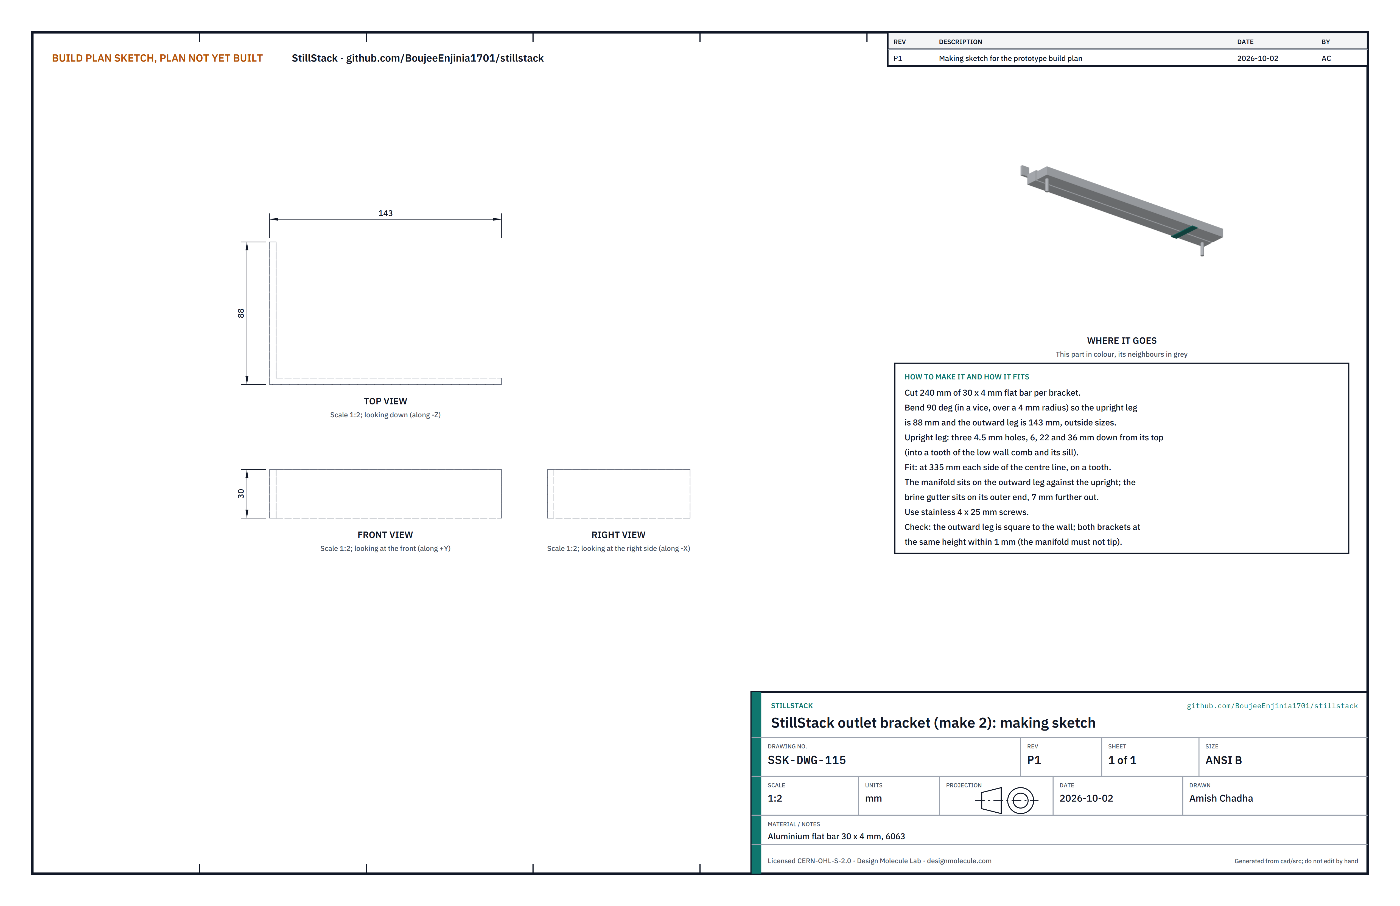
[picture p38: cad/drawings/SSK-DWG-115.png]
Figure 33. Making sketch of the outlet bracket


*Figure 33. Outlet bracket making sketch (SSK-DWG-115).*

**What it is and what it is made from.** Two L-shaped brackets on the low wall that carry the manifold and the brine gutter. Aluminium flat bar 30 x 4 mm.

**How to make it.**

1. Cut 240 mm of bar for each bracket.
2. Bend 90° in a vice over a 4 mm radius so the upright leg is 88 mm and the outward leg 143 mm, outside sizes.
3. Drill three 4.5 mm holes in the upright leg, 6, 22 and 36 mm down from its top.

**How it fits the parts next to it.**

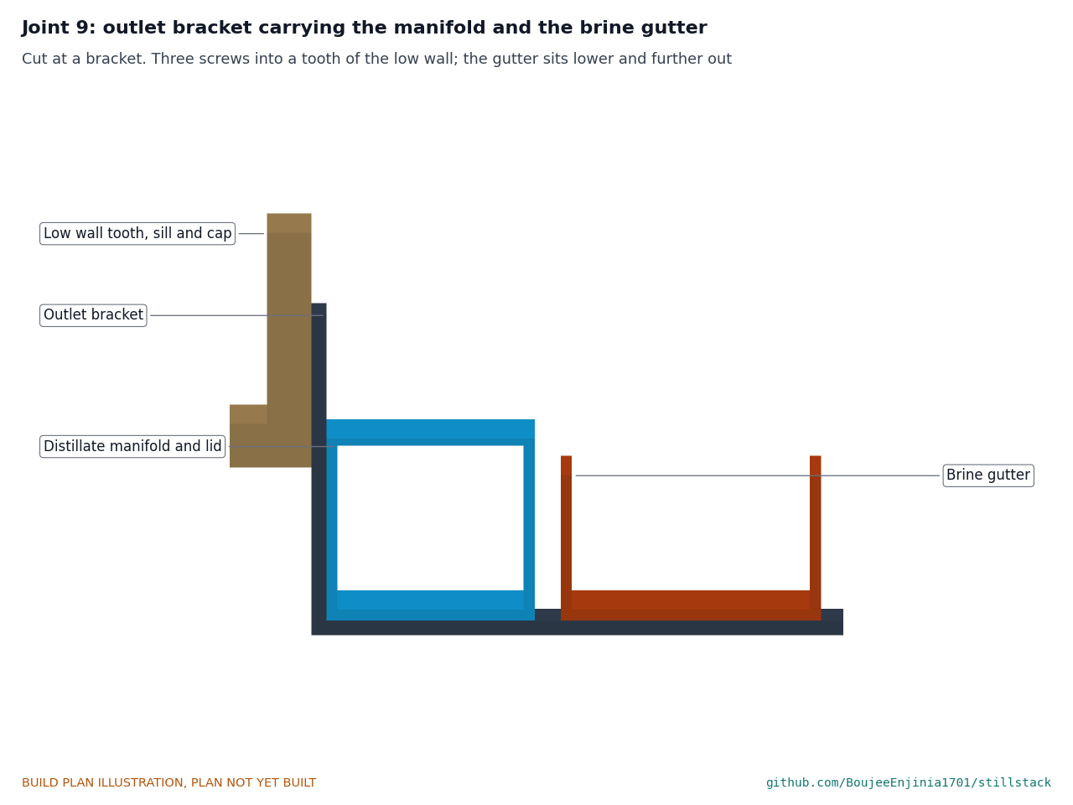
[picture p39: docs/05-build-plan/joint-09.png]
Figure 34. Joint 9: outlet bracket carrying the manifold and the brine gutter


*Figure 34. Cut at a bracket: the manifold sits against the upright; the gutter sits on the outer end, lower and further out.*

Each bracket is screwed (4 x 25 mm stainless) to a tooth of the low wall comb and its sill, 335 mm each side of the centre line.

**Check before moving on.** The outward legs are square to the wall and level with each other within 1 mm.

### 3.16 Ground frame

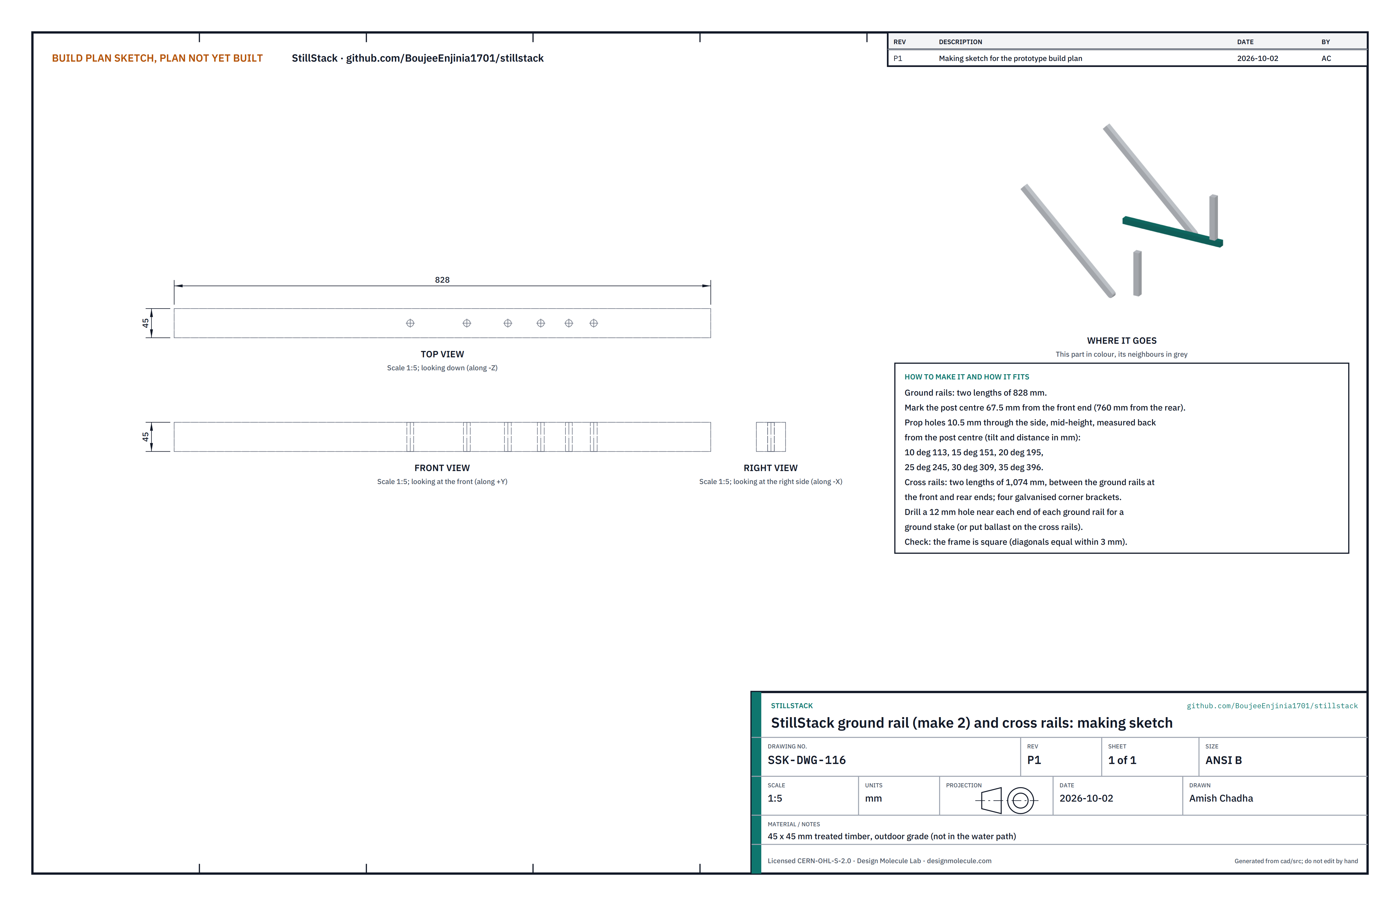
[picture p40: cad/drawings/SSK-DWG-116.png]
Figure 35. Making sketch of the ground rail


*Figure 35. Ground rail making sketch (SSK-DWG-116), with the six prop holes.*

**What it is and what it is made from.** Two ground rails and two cross rails that the stand stands on. 45 x 45 mm treated timber (it never touches the water).

**How to make it.**

1. Cut two ground rails 828 mm and two cross rails 1,074 mm.
2. On each ground rail, mark the post centre 67.5 mm from the front end.
3. Drill six 10.5 mm holes through the side, at mid-height, measured back from the post centre: 113 mm (10°), 151 mm (15°), 195 mm (20°), 245 mm (25°), 309 mm (30°) and 396 mm (35°). Drill the two rails clamped together.
4. Drill a 12 mm hole near each end of each ground rail for a ground stake.

**How it fits the parts next to it.** The cross rails fit between the ground rails at the front and rear ends with four galvanised corner brackets. The posts stand on the rails at their marks; the props pin to the outside of the rails.

**Check before moving on.** The frame is square, with diagonals equal within 3 mm.

### 3.17 Front posts and gussets (make 2 of each)

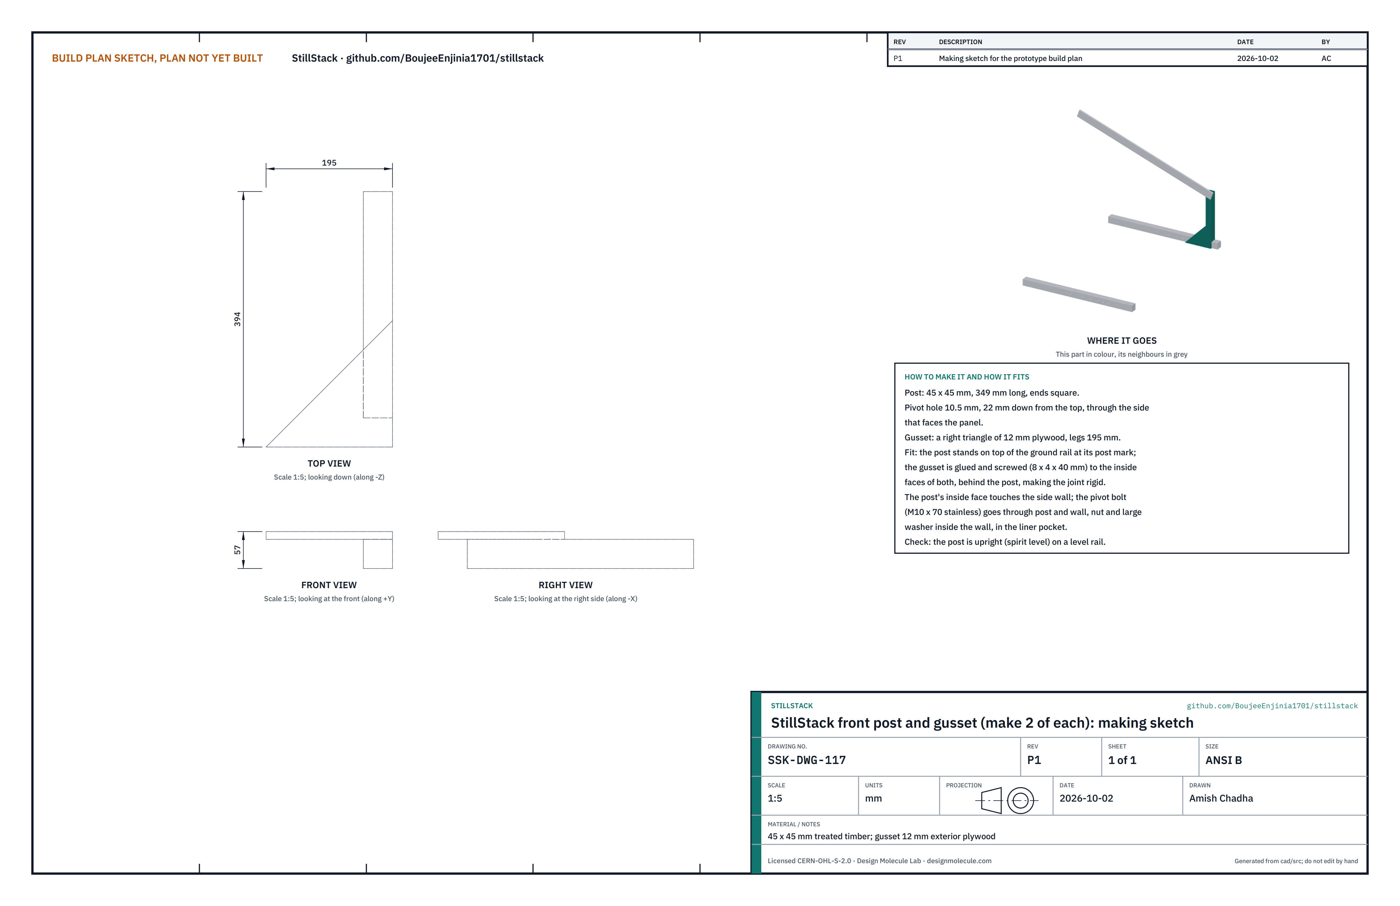
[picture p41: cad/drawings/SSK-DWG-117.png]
Figure 36. Making sketch of the post and gusset


*Figure 36. Front post and gusset making sketch (SSK-DWG-117).*

**What they are and what they are made from.** The posts that carry the panel's pivot, made rigid on the ground rails by plywood gussets. 45 x 45 mm treated timber; gussets 12 mm exterior plywood.

**How to make them.**

1. Cut two posts 349 mm long, ends square.
2. Drill the pivot hole 10.5 mm, 22 mm down from the top, through the side that faces the panel.
3. Cut two right-triangle gussets with legs of 195 mm.

**How they fit the parts next to them.**

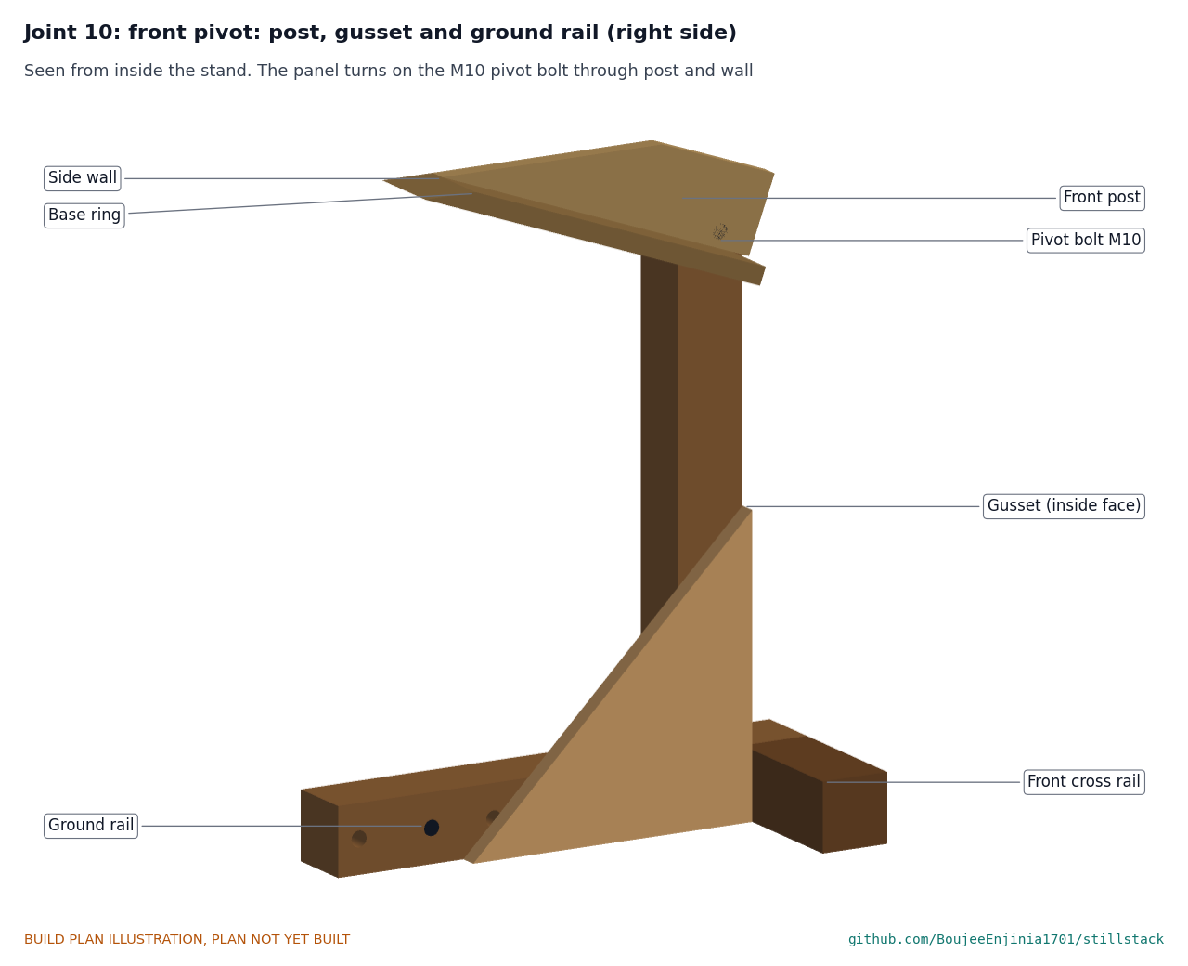
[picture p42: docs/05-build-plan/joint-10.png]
Figure 37. Joint 10: front pivot, post, gusset and ground rail


*Figure 37. Seen from inside the stand: the gusset joins post and rail behind the post; the M10 pivot bolt goes through the post and the side wall.*

Each post stands on top of its ground rail at the mark; the gusset is glued and screwed (eight 4 x 40 mm screws) to the inside faces of post and rail, behind the post. The post's inside face touches the side wall, and an M10 x 70 stainless bolt through post and wall, with a large washer and nut inside the wall in the liner pocket, is the pivot.

**Check before moving on.** Each post is upright on the level frame (spirit level).

### 3.18 Props (make 2)

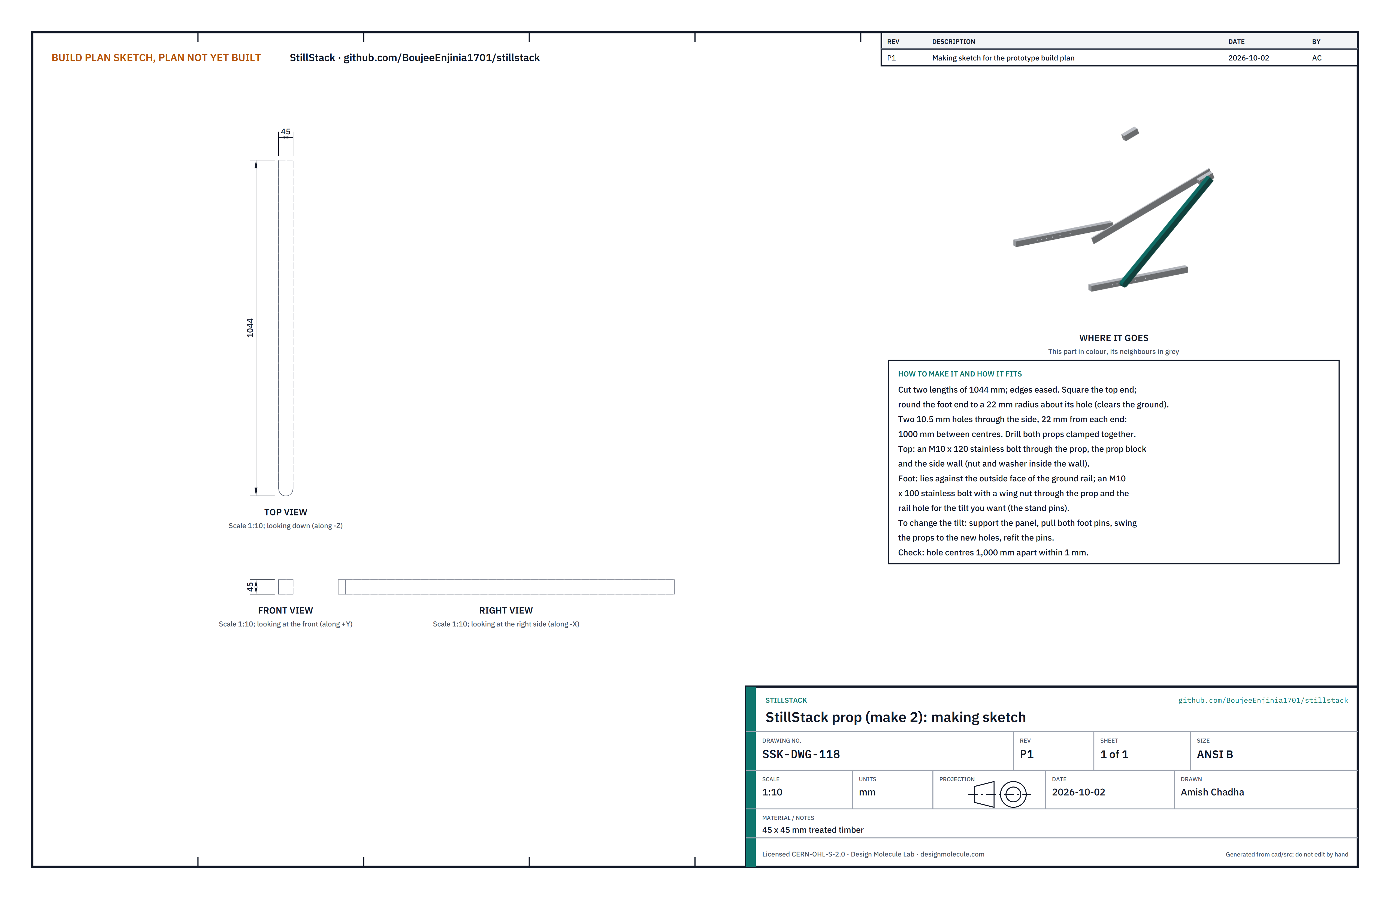
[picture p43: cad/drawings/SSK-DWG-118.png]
Figure 38. Making sketch of the prop


*Figure 38. Prop making sketch (SSK-DWG-118).*

**What it is and what it is made from.** A fixed-length strut on each side from the prop block to the ground rail; the hole it is pinned in sets the tilt. 45 x 45 mm treated timber.

**How to make it.**

1. Cut two lengths of 1,044 mm and ease the edges. Leave the top end square; round the foot end to a 22 mm radius about its hole so it clears the ground at every tilt.
2. Drill two 10.5 mm holes through the side, 22 mm from each end, 1,000 mm between centres, with the two props clamped together.

**How it fits the parts next to it.**

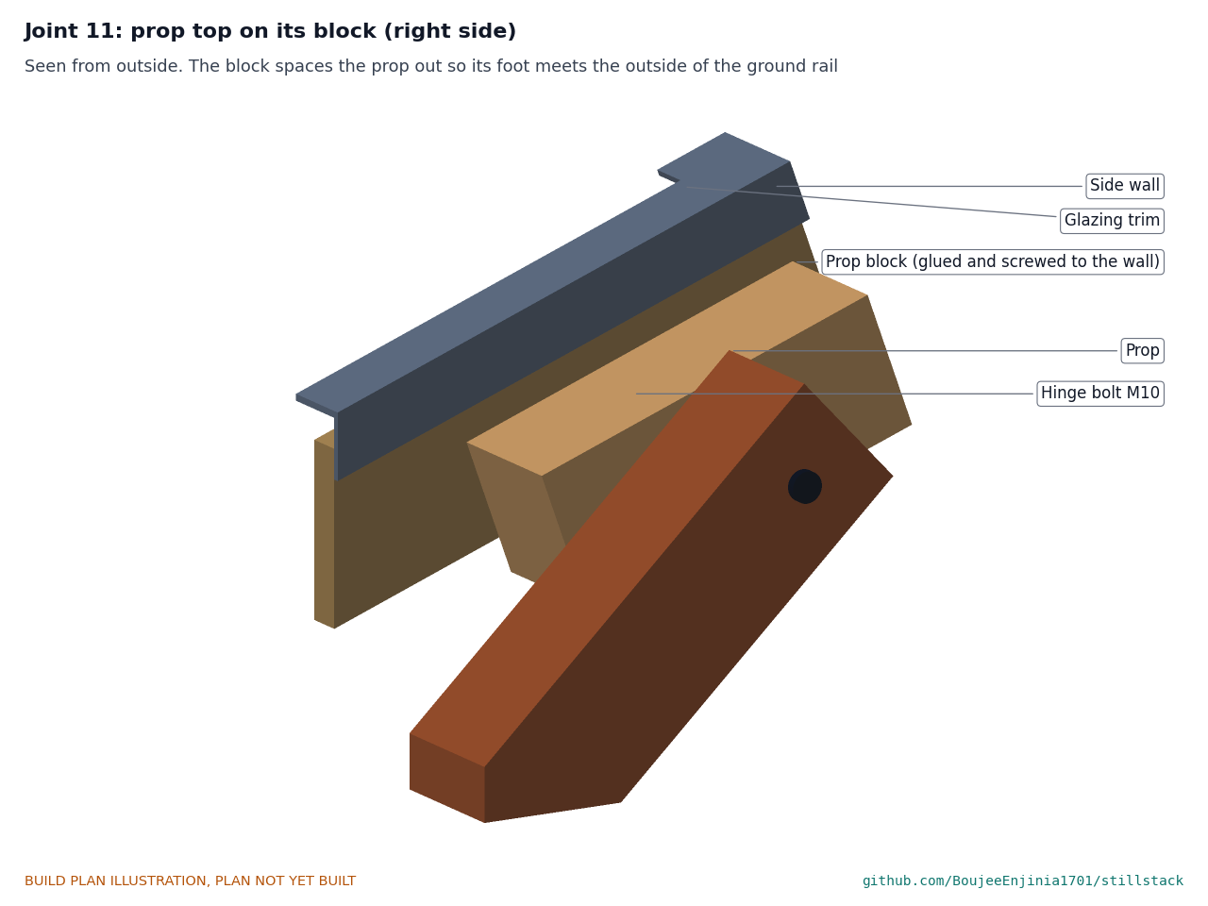
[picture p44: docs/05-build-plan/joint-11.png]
Figure 39. Joint 11: prop top on its block


*Figure 39. The prop hinges on an M10 bolt through the prop, the prop block and the side wall.*

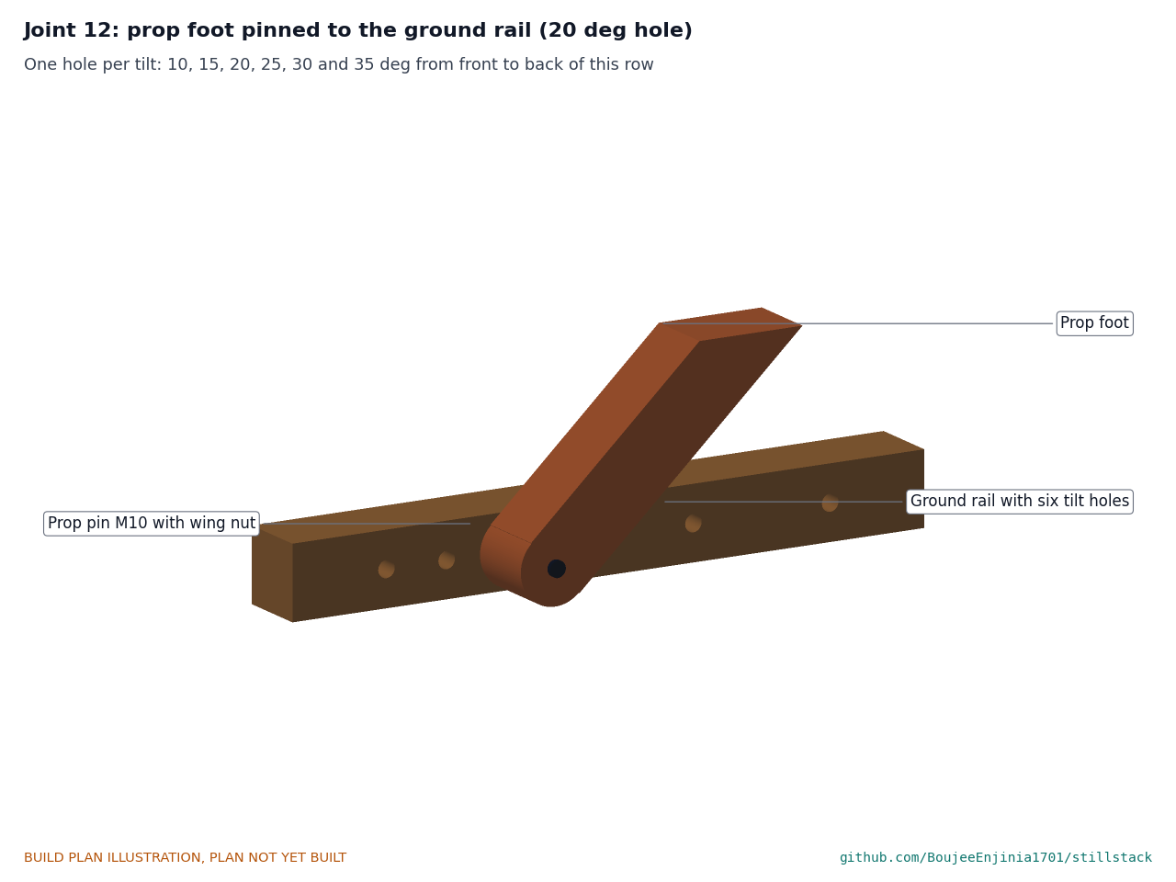
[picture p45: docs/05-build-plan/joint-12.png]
Figure 40. Joint 12: prop foot pinned to the ground rail


*Figure 40. The foot lies against the outside of the ground rail and is pinned through the hole for the chosen tilt.*

The top: an M10 x 120 stainless bolt through prop, block and wall, nut and washer inside the wall. The foot: an M10 x 100 stainless bolt with a wing nut through the prop and the rail hole for the tilt. To change the tilt, support the panel, pull both foot pins, swing the props to the new holes and refit the pins.

**Check before moving on.** Hole centres are 1,000 mm apart within 1 mm.

### 3.19 Bought components

Buy to specification, not brand. Line numbers are those of the bill of materials.

- **Glazing (line 1).** 6 mm twin-wall UV-stabilised clear polycarbonate, cut to 1,060 mm square with the flutes running down the slope; breather tape for the flute ends.
- **Liner (line 2).** Foil-faced stone wool board 25 mm, rated well above 150 °C, compressive strength 10 kPa or more.
- **Ribs (line 7).** 7 mm food-grade silicone round cord.
- **Feed trough (line 8).** PVC or HDPE gutter about 70 x 70 mm, 1.0 m, with end caps, a drip valve at the front end and two fascia gutter brackets.
- **Distillate manifold (line 9).** Food-grade PP or HDPE channel about 56 x 50 mm with a snap-on lid, 1.0 m, with an outlet near one end and silicone outlet tube to a clean covered container.
- **Brine gutter (line 10).** PVC gutter about 70 x 40 mm, 1.0 m, with an outlet at the other end and a drain hose.
- **Sealant, fasteners and tubing (line 13).** NSF/ANSI 51 or 61 food-grade silicone sealant; high-temperature silicone adhesive; exterior polyurethane glue; stainless screws (4 x 20, 4 x 25, 4 x 30 and 4 x 40 mm); silicone tube.
- **Stagnation cover (line 14).** Opaque white or aluminised tarpaulin 1.3 x 1.3 m with an elastic edge cord.
- **Glazing tape (line 15).** Silicone foam tape 3 x 30 mm, 4.3 m.
- **Feed closure (line 17).** Closed-cell silicone foam strip 5 x 35 mm, 1.0 m.
- **Wick clips (line 18).** 0.4 x 8 mm 304 stainless strip, about 5.5 m (one 6 m coil), cut and folded in the workshop.
- **Labels (line 19).** Two UV-stable vinyl or engraved aluminium labels, 80 x 25 mm, DISTILLATE beside the manifold outlet and BRINE beside the brine drain.
- **Stand hardware (line 12).** Two M10 x 70 and two M10 x 120 stainless bolts with nuts and large washers; two M10 x 100 stainless bolts with wing nuts; four galvanised corner brackets; four ground stakes.

## 4. Putting it together

In each picture the parts already fitted are grey and the parts being fitted are in colour, with an arrow showing the way they go in. Steps 1 to 18 are done with the panel lying level on a bench; steps 19 to 22 build the stand and put the panel on it.

### Step 1: end walls between the side walls

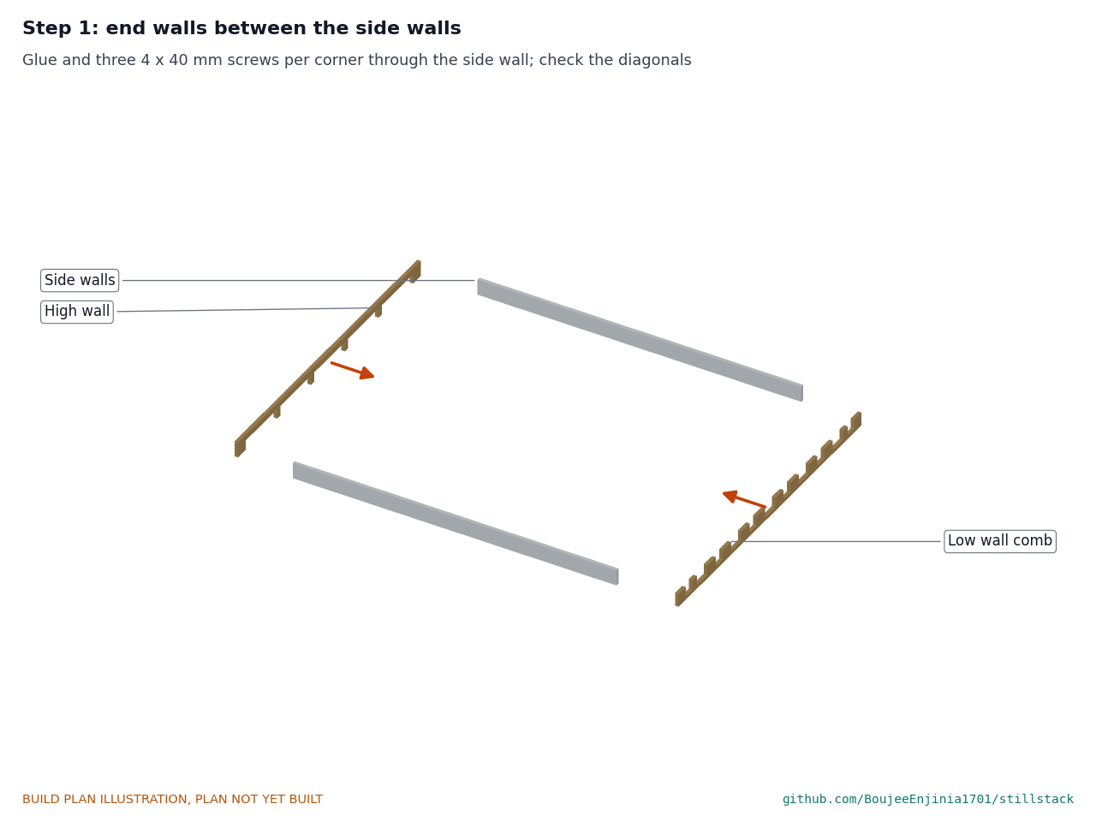
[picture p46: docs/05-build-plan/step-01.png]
Step 1


Glue and three 4 x 40 mm screws per corner through the side wall into the high wall and the low wall comb. Check the diagonals are equal within 2 mm before the glue sets.

### Step 2: base ring under the walls

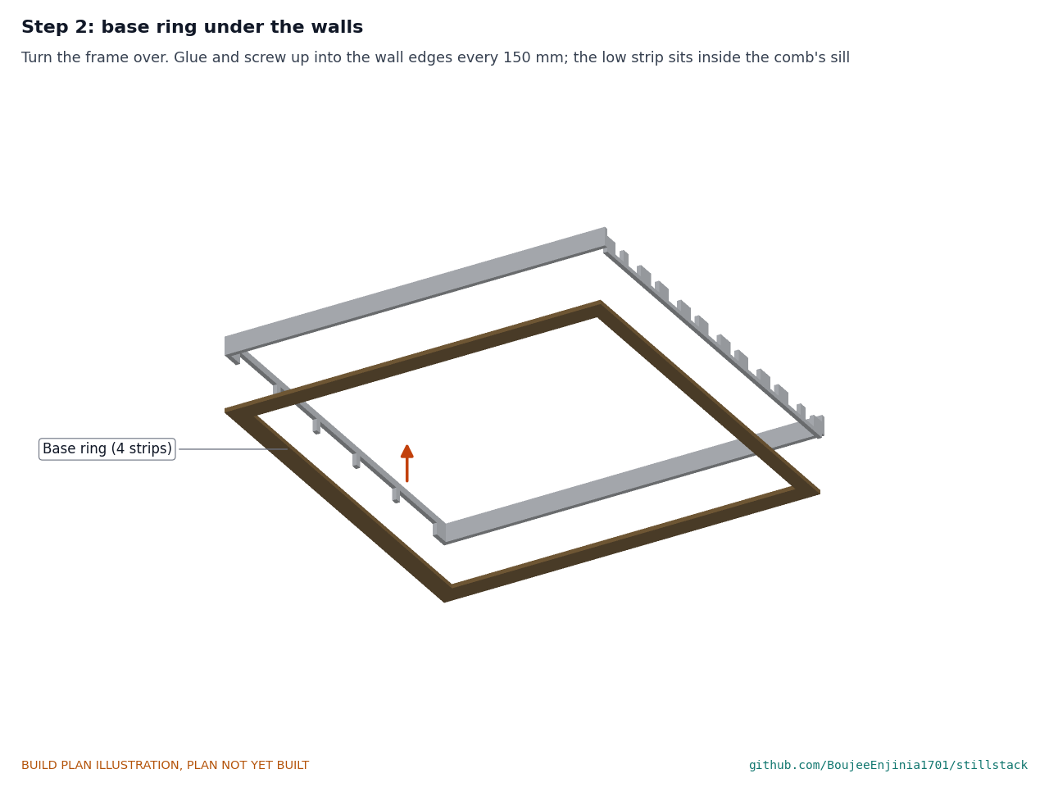
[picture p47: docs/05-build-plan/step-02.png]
Step 2


Turn the frame over. Glue and screw the four strips up into the wall edges every 150 mm; the low strip sits inside the comb's sill.

### Step 3: liner into the frame

Step 3

High-temperature silicone on the back of each piece, foil toward the stack, pockets behind the pivot and hinge holes. Keep the low blocks between the wall's notches.

### Step 4: stop blocks into the low corners

Step 4

High-temperature silicone on the back and side faces. The prop blocks are already on the side walls (section 3.1).

### Step 5: bottom plate and fins onto the base ring

Step 5

Lower it level, fins down; the six tongues drop into the comb's notches and rest on the sill. Its corners touch the stop blocks.

### Step 6: stage 4 rails, ribs and plate 3

Step 6

Lay the two stage 4 rails flush with the side edges, low ends on the stop blocks, and the four ribs on the rib lines. Lower plate 3, with wick 4 clipped under it (ten clips), so its tongues drop into the notches; feed the wick tails out through the high wall openings. Then run the chevron dams on plate 3's top face. **Hold point:** with a 6 mm gauge, the gap is even at the four corners and on each rib line.

### Step 7: stage 3 rails, ribs and plate 2

Step 7

As step 6, with the stage 3 rails and plate 2 (wick 3 clipped under it); then the dams on plate 2.

### Step 8: stage 2 rails, ribs and plate 1

Step 8

As step 6, with the stage 2 rails (PPS) and plate 1 (wick 2 clipped under it); then the dams on plate 1.

### Step 9: stage 1 rails, ribs and the absorber

Step 9

As step 6, with the stage 1 rails (PPS) and the absorber (wick 1 clipped under it), black face up. **Hold point:** no wick fibre bridges a dry break, every tail is centred on its brine tongue, and no tongue touches the side of its notch.

### Step 10: low wall cap

Step 10

Sits on the comb's teeth over the tongues; two 4 x 30 mm screws into the side walls' end grain.

### Step 11: glazing tape and glazing

Step 11

Tape on the wall tops, glazing on the tape with the flutes running down the slope and the flute ends sealed with breather tape, 7 mm clear of the outside of the walls all round.

### Step 12: glazing trim

Step 12

A bead of silicone under the top leg; 4 x 20 mm stainless screws every 200 mm through the hanging leg into the walls.

### Step 13: outlet brackets onto the low wall

Step 13

Three 4 x 25 mm stainless screws each into a tooth of the comb and its sill, square to the wall and level with each other.

### Step 14: distillate manifold and lid

Step 14

Snap the lid onto the channel first. Slide the manifold in from outside, under the straight tongues, onto the brackets and against their uprights, outlet at the right-hand end as you face the low wall, with the lid's slots under the distillate tongues.

### Step 15: bend the distillate tongues into the lid slots

Step 15

Lowest plate first, bend each tongue down over a hardwood block at its bend line so it drops 3 mm into the channel through its slot. **Hold point:** no distillate tongue touches a brine tongue or a wick tail.

### Step 16: brine gutter onto the bracket ends

Step 16

Outboard of and lower than the manifold, drain at the left-hand end, away from the distillate outlet.

### Step 17: bend the brine tongues into the gutter

Step 17

Lowest first, each 4 mm outside the one below, so each ends inside the gutter with its wick tail under it. **Hold point:** every brine tongue and tail is at least 10 mm above the closed lid along its whole length (use a 10 mm gauge).

### Step 18: feed trough and foam closure

Step 18

Screw the two fascia brackets to the high wall's solid ends; glue the foam strip to the trough's inner wall; set the trough in the brackets and lead every feed tail up the wall, over the rim and down into the trough.

### Step 19: ground frame

Step 19

Cross rails between the ground rails with the four corner brackets. Set the frame level on firm ground and stake or ballast it.

### Step 20: front posts and gussets

Step 20

Each post on top of its rail at the mark; gusset glued and screwed to the inside faces behind the post.

### Step 21: panel onto the front posts

Step 21

Two people, panel dry, cover on. Lift the panel between the posts, fit the M10 pivot bolts through posts and side walls, and rest the high end on a trestle. **Hold point:** safety stop S4 in section 6.

### Step 22: props from the prop blocks to the tilt holes

Step 22

M10 hinge bolt through each prop, block and wall; foot pin with wing nut through the rail hole for the tilt wanted (20° shown). Remove the trestle only when both pins are in.

## 5. First checks

These are the checks a TRL 4 test report would record; this plan only lists them. Requirement numbers are those of SSK-REQ-001.

*Table 2. First checks.*

| Check | Requirement | How | Pass when |
| --- | --- | --- | --- |
| Gaps | R1, R2 | 6 mm gauge at the corners and rib lines of every gap during steps 6 to 9 | Every gap 6 mm, give or take 0.5 mm |
| Dry breaks and brine clearance | R4 | Look along every wick edge; 10 mm gauge between each brine tongue or tail and the lid | 10 mm of dry plate beside every rib and rail; 10 mm or more everywhere above the lid |
| Separation, coloured water | R4, R3 | Panel at 20° in shade, cover on; food dye in the feed; run 2 hours | No colour in the manifold or its outlet |
| Wicks lift out | R10 | Slide off the tongue clips, unhook the high-end clips, lift one wick strip and refit it; time it | A strip comes out and goes back in a few minutes without tearing |
| Plates lift out | R10 | Remove the cap, lift the absorber and one condenser plate, refit; time it | The plates come out and go back without bending a tongue |
| Tilt range | R11 | Pin the props at each of the six holes; angle finder on the glazing | 10° to 35°, each within 1° of its hole |
| Mass and footprint | R9 | Weigh the panel dry; measure the stand at 10° | 20 kg or less dry (18.7 kg estimated); within 1.3 x 1.3 m |
| Feed head | R5 | Measure the trough rim height at 35° | 1.5 m or less (1.00 m estimated) |
| Food-contact surfaces | R7 | Check the coating, manifold, lid, tube and silicone against their datasheets | Every distillate-side surface food-contact rated |
| First sun | R1, R2, R8 | Feed running, cover off, a clear day; outputs per stage and absorber temperature logged | Recorded for the TRL 4 report; feed never runs out |
| Distillate quality | R3 | Conductivity of each stage's distillate | 75 µS/cm or less |

## 6. Safety stops

Stop at each point. Carry on only when everything listed is true.

- **S1. Before cutting.** Gloves and glasses for aluminium sheet and snips; gloves, glasses and a dust mask for stone wool; hearing protection for the jigsaw; a ventilated space for paint, primer and the printer.
- **S2. Before painting the absorber or coating the plates.** Ventilation and a respirator as the product's datasheet says; no flame nearby; cure to the maker's schedule before the plate goes in.
- **S3. Before closing the stack (step 10).** Every surface on the distillate side (coating, lid, manifold, tube, silicone) is food-contact rated; no treated timber, lead solder or container of unknown history anywhere in the water path.
- **S4. Before lifting the panel onto the stand (step 21).** Two people; the panel dry (about 18.7 kg); the ground frame staked or ballasted; the cover on.
- **S5. Before the panel faces the sun.** The stand staked or ballasted (the panel can overturn at about 18 m/s of wind); the feed container full and the drip valve open; the stagnation cover at hand. Never leave the panel in sun with an empty feed: a dry stack reaches about 140 °C.
- **S6. Before opening or working on the stack.** The cover on and the panel cool to the touch.
- **S7. Before anyone drinks the distillate.** Tested for at least conductivity and E. coli, stored in a clean covered container and disinfected. The prototype's distillate is test water until then.
- **S8. Brine.** Led to a soak-away or evaporation pond away from crops, wells and soil that must stay fresh.

## 7. Tools, skills and workspace

**Tools.** Circular saw or a fine-toothed handsaw with a straight-edge guide for ripping plywood; jigsaw with wood and fine metal blades; drill with bits from 2.5 to 12 mm; chisel and mallet; files and a deburring tool; aviation snips; two straight hardwood battens and a vice for folding the fins; two steel plates and tin snips for the stainless clips and the lip tabs; steel rule, engineer's square, angle finder and spirit level; a 6 mm and a 10 mm gauge (offcuts of rail stock); long bread knife for the stone wool; caulking gun; screwdrivers; clamps; a 3D printer with an enclosure and a heated bed that prints polycarbonate; a scale to 30 kg.

**Skills.** No certified trade is needed. Basic woodwork (ripping, notching, gluing and screwing), cutting and folding thin aluminium sheet, careful cutting of fabric and insulation board, printing polycarbonate, and neat work with silicone. There is no electricity in the product.

**Workspace.** A flat bench at least 1.3 x 1.3 m, or two trestles with a sheet of plywood; a clean area kept apart from sawdust for coating the plates and fitting the wicks; a ventilated place for paint and printing; a shaded outdoor spot for the stand.

**Personal protective equipment.** Safety glasses throughout; cut-resistant gloves for aluminium; gloves and a dust mask for stone wool; hearing protection for sawing; a respirator for spray paint or coating as their datasheets say.

## 8. Where the numbers come from

- Model and constructability checks: `cad/src/model.py` (`python cad/src/model.py --check`); STEP and STL exports in `cad/step/` and `cad/stl/`.
- Pictures: `cad/src/build_plan_media.py`, using `.kit/build_views.py`; written to `docs/05-build-plan/` and `cad/drawings/SSK-DWG-101` to `SSK-DWG-120`.
- General arrangement: `cad/drawings/SSK-DWG-002.pdf`, Rev P4.
- Calculations: `docs/04-calcs/01-sizing.md` (SSK-CAL-001 v0.6) and `docs/04-calcs/sizing.py`; plate support [section 3], mass, tilt and footprint [section 8], wind [section 9], construction checks [section 13].
- Bill of materials: `bom/bom.csv`.
- Decisions: `docs/decisions/0003-design-for-construction.md` (SSK-DDR-003), with SSK-DDR-001 and SSK-DDR-002; open items in `docs/06-design-decisions.md` (SSK-DEC-001).
- Requirements: `docs/03-requirements.md` (SSK-REQ-001 v0.8).

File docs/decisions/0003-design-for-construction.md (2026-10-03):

---
doc_id: SSK-DDR-003
title: StillStack design for construction
project: StillStack
doc_type: Design decision record
version: "0.3"
status: Draft
date: '2026-10-02'
author: Amish Chadha
license: CERN-OHL-S-2.0
revisions:
- version: "0.1"
  date: '2026-10-01'
  author: Amish Chadha
  change: Changes that make the concept physically buildable, with the reason for each; made under Amish's 2026-09-30 instruction to make the design physically buildable; open for his review
- version: "0.2"
  date: '2026-10-02'
  author: Amish Chadha
  change: "Accepted by Amish (2026-10-02) with exceptions: A2 decided as option (c), P11 wick fixing replaced by clips; A1 as recommended; status kept Draft"
- version: "0.3"
  date: '2026-10-02'
  author: Amish Chadha
  change: "Exceptions carried into the model, drawings, BOM and calculations (lip tabs, wick clips, PPS rails, labels); mass, cost and drawing figures updated"
---

# 0003: Design for construction

- **Date:** 2026-10-01
- **Status:** accepted, with exceptions. Amish, 2026-10-02: "i approve your recommendations for all 555 open decisions." The changes in Tables 1 and 2 are accepted as made, with two exceptions decided in the design decisions register (SSK-DEC-001): A2 is decided as option (c), a 4 mm downturned lip on each condensing plate's high edge, not the (a) the model and build plan show; and the silicone dots of P11 are replaced by clips at each wick's high and low ends with no adhesive. A1 is accepted as recommended, with each stage's distillate conductivity test a pass condition at TRL 4 before any water is drunk. The model and the build plan pictures still show option (a) of A2 and the silicone dots until they are updated.

## Context

On 2026-09-30 Amish asked for a build plan that shows how each component is made and how it fits the next, and wrote: "If you are realising that the design cannot be built as per concept - fix the design assumptions to match and be physically feasible as you draw the illustrations." The concept model (SSK-DDR-002) showed what StillStack does but left several parts that could not be made, fixed or assembled as drawn. Checking the model with build123d found twelve (P1 to P12 below).

The changes keep what the panel does: the same 1 m2 aperture, four stages with 6 mm gaps, plate and wick materials, ribs at 194 mm pitch, 25 mm air gap and twin-wall glazing, air-cooled fins, gravity feed from a trough at the high edge, a lidded distillate manifold and a brine gutter outboard of and lower than it at the low edge, and a stand adjustable from 10 to 35 deg. Every change is in `cad/src/model.py`, which now runs 93 constructability checks (`python cad/src/model.py --check`): no overlaps among the 46 panel parts, every contact that must exist does, every brine path keeps 10 mm from every distillate path, and the stand is checked at each of its six tilt holes.

## Decision

*Table 1. Changes made to the model, the BOM and the calculations (Draft, open for Amish's review).*

| # | Problem in the concept | Change made | Why this way |
| --- | --- | --- | --- |
| P1 | The stack sat on a 5 mm "ledge" of no stated material along the two side walls only; the bottom plate had nothing under its high and low edges and nothing under its middle. | A 12 mm plywood base ring (four strips) under the walls, with a 15 mm ledge into the aperture on all four sides. The bottom plate rests on the ledge all round and spans 970 mm between the high and low ledges as ten fin-stiffened strips; the side rails sit directly over the side ledges. | The ribs bring the stack's weight (108 N/m2) down onto the bottom plate; with its fins bonded it sags about 0.5 mm (1.0 mm on the fins alone), and the whole stack moves together, so the gaps stay at 6 mm (SSK-CAL-001 section 13). |
| P2 | The low wall had four 996 x 2 mm slits for the plate lips, leaving 5.5 mm slivers of plywood that cannot be cut or survive, and a plate with a lip cannot be put through a slit from inside the frame. | The low wall is a comb: a 12 mm sill along the bottom and teeth between eleven open-topped notches 33 mm deep, with a separate cap strip (and its liner) that closes the notches above the stack. | Each plate drops in from above with its tongues in the notches. Lifting the cap lets the plates come out again, which also helps R10. |
| P3 | The brine exit at the low edge was not detailed (R4 at risk): wick tails had to cross the distillate lips, which sit 7.5 mm apart in the same edge. | The plates' low edges are cut to a zigzag. Distillate leaves on six 30 mm tongues at the rib lines and corners, which turn down through slots in the manifold lid. Brine leaves on five 50 mm tongues at the strip centres, each carrying a 30 mm wick tail underneath, over the closed lid and down into the brine gutter. A silicone chevron dam at each brine tongue root turns condensate aside. See A1. | Brine and distillate are separated across the panel's width, not stacked, so every brine path keeps at least 10.5 mm (over the lid) and 44 mm (sideways) from every distillate path. |
| P4 | Nothing stopped the plates and rails sliding down the slope: the lips slid freely in their slits and the plate ends faced soft stone wool. | Two stop blocks, cut from the stage 1 rail polymer, fill the liner's low corners. The plate corners and the rail ends bear on them, and they bear on the low wall. | A hard face where the stack's down-slope load (up to sin 35 deg of its weight) goes into the plywood. |
| P5 | The glazing floated 4 mm below a frame lip with no fixing, in an opening its own size, with no room for the 4.8 mm it grows when hot. | A 1,060 mm square sheet on 3 mm silicone foam tape on the wall tops, held by a mitred aluminium trim (25 x 20 x 2 mm angle) screwed to the walls. The walls end under the tape (52.5 mm tall). | 7 mm of room each side for growth; the trim stops 14 mm outside the aperture, so it casts no shade. This adopts item 1 of the 2026-09-26 product model review. |
| P6 | The wicks "drape over the frame wall into the trough", but the wall rises above the stack and the trough had no fixing. | Five feed openings in the high wall, one per wick strip; each tail runs out, up the outside of the wall and over the trough rim. A silicone foam strip on the trough's inner wall closes the openings around the tails. The trough hangs on two fascia gutter brackets screwed to the wall's solid ends. | Feed reaches each stage without crossing anything but the wall; the closure keeps vapor in and dust out. |
| P7 | The manifold and brine gutter had no support or fixing. | Two outlet brackets (30 x 4 mm aluminium flat bar, bent to an L) screwed to teeth of the low wall comb carry the manifold against their uprights and the gutter on their outer ends. | The gutter sits 10 mm lower and 7 mm outboard of the manifold, as the concept requires. |
| P8 | The fins had no fixing and their ends ran into the zigzag edge and the ledge. | Fins 940 mm long, bonded by their 20 mm flange with high-temperature silicone adhesive, 15 mm clear of the ledge. | Bonding leaves the condensing face above unpierced. |
| P9 | The rear struts were vertical posts from the ground, but the frame's high edge moves about 90 mm along the ground as the tilt changes, and a frame on pinned posts is a mechanism. | Ground frame (two rails, two cross rails); front posts on the rails, made rigid by plywood gussets; an M10 pivot bolt through each post and side wall; fixed-length props (1,000 mm between pins) hinged on blocks near the high end and pinned to the rail at one of six holes (10 to 35 deg in 5 deg steps). The rails run 760 mm behind the pivot. | Each side is a rigid triangle at every tilt. The centre of mass stays at least 260 mm inside the ground frame; the footprint is 1.28 x 1.25 m, within R9. |
| P10 | The walls had no corner joints. | Butt joints, glued and screwed through the side walls; the base ring and the trim tie the corners top and bottom. | Plain joints a home workshop can make. |
| P11 | "Wicks bonded under the plates" gave no method. | Dots of food-grade silicone every 100 mm along both edges of each strip. Replaced on 2026-10-02 (SSK-DEC-001): clips at each wick's high and low ends, no adhesive. | Holds the strip without sealing its face; R10 (removal) stays open. Clips let the wicks lift out for rinsing. |
| P12 | Ribs ran to the plate edge, across the new tongue mouths. | Ribs stop 8 mm short of the tongue tips. | Condensate reaches the distillate tongues unobstructed. |

*Table 2. Knock-on changes.*

| Item | Change | Reason |
| --- | --- | --- |
| Yield | Wet wick fraction 0.824 to 0.817; design-day yield 10.6 L and gained output ratio 1.26 to 1.34 unchanged at the precision quoted. Low-end vapor loss 25 mL per day (0.2 %). | Wicks stop 13 mm inside the zigzag edge. |
| Mass | Panel 18.7 kg dry (was 16.7), 22.7 kg wet; stand 8.9 kg, with the wick clips, PPS rails and stop blocks. R9 (20 kg dry) still met. | Base ring, trim, tongues, brackets. |
| Cost | Value-engineering target: USD 355. Estimated cost of the constructable design: USD 443.20 (USD 88.20 over the target, after the decisions of 2026-10-02 added USD 27); the concept priced at USD 351.20. New BOM lines 15 to 19; lines 2 to 5, 8, 11 and 12 respecified. | Larger plate blanks, trim, stand ground frame, brackets, closure. |
| Footprint and wind | 1.28 x 1.25 m at 10 deg (was 1.28 x 1.16 m); lift equals weight at 18.7 m/s (was 17.5 m/s). | Props sit outside the posts. |
| Drawings | SSK-DWG-002 Rev P4; making sketches SSK-DWG-101 to 120 added (119 and 120 are the wick clips); concept blueprint SSK-DWG-001 Rev P5. | Follow the model. |
| Documents | SSK-CAL-001 v0.6, SSK-PRC-001 v0.8, SSK-REQ-001 v0.8. R12 is reported against the value-engineering target; R10 moved from at risk to met on paper when the wick clips were modelled. | Follow the model. |

*Table 3. Items proposed to Amish; decided on 2026-10-02 (A1 as recommended, A2 as option (c)).*

| # | Question | Options | Recommendation |
| --- | --- | --- | --- |
| A1 | How brine leaves the low edge without reaching the distillate (R4; part of the safety case, because brine in the distillate is a drinking-water hazard). | (a) zigzag edges with distillate tongues at the rib lines and brine tongues at the strip centres, as modelled (P3); (b) a cross-wick along the low edge of each stage that carries brine sideways to tails at the side walls; (c) leave the low edge as in the concept and test the brine exit separately at TRL 4. | (a): it keeps the concept's layout (brine over the closed manifold lid into an outboard, lower gutter) and every brine path at least 10 mm from every distillate path. Confirm by measuring each stage's distillate conductivity at TRL 4. Accepted 2026-10-02: each stage's distillate conductivity test is a pass condition at TRL 4 before any water is drunk; the cross-wick (b) is the fallback. |
| A2 | The feed tails leave each wick at the high edge 6 mm above the condensing plate below; if a tail sags or drips there, feed water could reach a condensing face (found in this review; R4, safety case). | (a) accept for the first prototype and measure each stage's distillate conductivity at TRL 4; (b) stagger the plates' high edges about 22 mm per level so each tail leaves clear of the plate below (costs about 4 % of the yield); (c) a 4 mm downturned lip on each condensing plate's high edge. | (a), with (c) as the first fix if the conductivity test shows carryover. Decided 2026-10-02 as (c) now: a 4 mm downturned lip, bent before coating, dropped only if TRL 4 conductivity tests without it show no carryover. |

## Consequences

- `design_state: constructable` in `project.yaml`. The build plan SSK-BLD-001 shows every component and step in pictures generated from the model (`cad/src/build_plan_media.py`), and the design decisions register SSK-DEC-001 lists A1, A2 and the other open items.
- Exceptions accepted on 2026-10-02: the high-edge lip of A2 (c) and the wick clips that replace P11's silicone dots are carried into the model, the plate and wick sketches, the BOM and the build plan pictures (2026-10-02). The lip is four 7 mm tabs on the rib lines of each condensing plate, not a full-width lip, because the wicks of the plate pass out of the same edge; the base ring has four slots for the bottom plate's tabs.
- Requirement status is unchanged except that R12 is now reported against the value-engineering target: none not met, five at risk (R2, R4, R6, R7, R8), one not verifiable at TRL 3 (R3), five met on paper (R1, R5, R9, R10, R11), and R12 USD 88.20 over the target.
- The photoreal renders (`media/render-*.png`), `media/card.png`, `media/social-preview.png` and the appearance model `cad/src/product_model.py` are being redone: the appearance model now follows the constructable design and the render scenes are exported; the images are made on Amish's Mac, where Blender is.
- The plate tongues stay straight until the manifold and gutter are fitted, then are bent by hand (build plan steps 15 and 17).

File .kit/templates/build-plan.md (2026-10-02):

---
doc_id: PRJ-BLD-001
title: Project prototype build plan
project: Project name
doc_type: Build plan
version: "0.1"
status: Draft
date: YYYY-MM-DD
author: Amish Chadha
license: CERN-OHL-S-2.0
revisions:
  - version: "0.1"
    date: YYYY-MM-DD
    author: Amish Chadha
    change: First build plan; design made constructable
---

# Project prototype build plan

**Plan, not yet built.** How to build the first proof-of-concept prototype, component by component. Building and testing to it is TRL 4 work. Decisions still to be made are kept in the design decisions register (`docs/06-design-decisions.md`), not here.

## 1. What you are building

Every component, pulled apart and numbered in build order

One short paragraph: what the prototype is, how many components, which are made and which are bought, and the main ways they are made.

## 2. What changed to make it buildable

| Component | The concept had | The buildable design has | Why |
| --- | --- | --- | --- |

## 3. Making the components

### 3.1 Component name

Making sketch

**What it is and what it is made from.**

**How to make it.**

1. Mark out ...
2. Cut ...

**How it fits the parts next to it.**

Close-up of the joint

**Check before moving on.**

## 4. Putting it together

### Step 1: ...

Step 1

## 5. First checks

| Check | Requirement | How | Pass when |
| --- | --- | --- | --- |

## 6. Safety stops

## 7. Tools, skills and workspace

## 8. Where the numbers come from

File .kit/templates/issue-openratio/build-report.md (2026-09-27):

---
name: Build report
about: Tell us what happened when you built, printed or tested part of this design
title: "Build report: "
labels: build-report
---

This is a research and educational prototype, not a medical device. It is a TRL 3 concept and is not released for fabrication. If you build any part of it, you do so at your own risk. Reports help everyone.

**What you built** (part, sub-assembly or test)

**Materials, tools and settings**

**What worked**

**What did not work, with photos or measurements if you have them**

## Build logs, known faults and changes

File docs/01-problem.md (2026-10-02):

---
doc_id: SSK-PRB-001
title: StillStack problem statement
project: StillStack
doc_type: Problem statement
version: "0.6"
status: Draft
date: '2026-10-02'
author: Amish Chadha
license: CERN-OHL-S-2.0
revisions:
- version: "0.1"
  date: '2026-09-24'
  author: Amish Chadha
  change: Initial scaffold
- version: "0.2"
  date: '2026-09-24'
  author: Amish Chadha
  change: Populate to TRL 2 (users, context, constraints, out of scope, prior work)
- version: "0.3"
  date: '2026-09-25'
  author: Amish Chadha
  change: Record the 1 m2 aperture decision (SSK-DDR-001) and the TRL 3 cost finding; partner question stays open
- version: "0.4"
  date: '2026-09-25'
  author: Amish Chadha
  change: Recommendations accepted by Amish (DDR-002)
- version: "0.5"
  date: '2026-09-26'
  author: Amish Chadha
  change: Budget top-up approved by Amish
- version: "0.6"
  date: '2026-10-02'
  author: Amish Chadha
  change: "Partner decided and first candidate to approach (SSK-DEC-001, 2026-10-02)"
---

# StillStack problem statement

Solar stills are the simplest way to turn salty or brackish water into drinking water without fuel or grid power, but a single-basin still makes only about 3 to 5 L per m2 per day, so a household needs 3 to 5 m2 of glazed basin to cover drinking and cooking water. That area is too large, too costly and too hard to maintain for most of the people who need it.

## The problem

A single-basin still throws away almost all of the energy it collects. Sunlight evaporates water from a shallow basin, the vapor condenses on the glass cover, and the latent heat released there (about 2.26 MJ per kg of water) is lost to the sky. The result is a daily efficiency of roughly 30 to 45 % of the solar input, which caps output at about 3 to 5 L per m2 per day under good sun. The deep water basin also takes hours to warm up each morning.

Multi-effect distillation fixes this in industry by condensing the vapor from one effect against the evaporator of the next, so the same heat evaporates water several times. Research groups have shown that the same idea works passively at small scale: thin wicks pressed against stacked metal plates, heated by sunlight from above, each stage reusing the heat of condensation from the stage above it. Laboratory prototypes of this kind (for example the passive multistage devices reported by Chiavazzo and colleagues in Nature Sustainability in 2018 and the thermally localized multistage still reported by Xu and colleagues in Energy and Environmental Science in 2020) produced two to four times the output of a basin still per unit area under simulated or real sun. There is still no open, documented, garage-buildable design that a community workshop, NGO or school can build, audit and adapt.

## Users and context

| User | Need | Context |
| --- | --- | --- |
| Household in an arid or saline coastal area | 5 to 15 L per day of safe drinking and cooking water from seawater or brackish well water | Rooftop or yard, no reliable grid, strong sun (5 to 7 kWh per m2 per day) |
| Rural clinic or school | A steady supply of low-salt water for drinking, and for rinsing and battery top-up | Small compound, a caretaker with basic tools, part-time maintenance |
| Small island or remote outpost | Backup water when a reverse osmosis unit or its power fails | Seawater feed, salt spray, high UV |
| NGO, makerspace or technical college | A reproducible, inspectable design to build, test and improve | Workshop with hand tools, a 3D printer and sheet metal tools |

## Constraints

- Garage-buildable prototype of 1 m2 aperture for about $355 USD in parts, using sheet aluminum, polycarbonate glazing, timber and cloth wicks. The 1 m2 aperture was confirmed by Amish on 2026-09-25 (SSK-DDR-001), the budget was raised from $250 to $320 the same day (SSK-DDR-002), and Amish approved a top-up to $355 on 2026-09-26. The priced BOM, including the 150 °C materials and stagnation cover decided in SSK-DDR-002, comes to about $351, so the cost constraint is met (SSK-CAL-001).
- Fully passive: no pumps, electronics or batteries. Feed water arrives by gravity from a container the user fills.
- Every surface that touches distillate must be food-contact safe, and all materials must tolerate dry stagnation under full sun.
- Feed water may be seawater (about 35 g per L of salt) or brackish groundwater, so wicks and plates must resist salt build-up and corrosion.
- Maintenance by a non-specialist with no special tools: rinsing or replacing wicks, clearing salt.
- Distillate is a raw product. It is not assumed to be safe to drink until tested, and the documentation must say so.

## Out of scope

- Certified drinking water treatment or any claim of potability.
- Brine disposal or salt recovery beyond a drain outlet.
- Large community plants (more than about 10 m2) and powered or hybrid (photovoltaic plus heater) versions.
- Water quality testing equipment and remineralization systems, which are named as needs but not designed here.

## Open questions

- Which users to involve first, and through which partner? Decided by Amish, 2026-10-02 (SSK-DEC-001): a university water or desalination lab first, to measure distillate quality; first candidate to approach, the Politecnico di Torino group behind the 2018 floating multistage still. A coastal NGO follows for field use once the distillate passes its tests. Nothing is agreed yet.
- The first size is settled: a household unit of 1 m2, decided by Amish on 2026-09-25 (SSK-DDR-001).

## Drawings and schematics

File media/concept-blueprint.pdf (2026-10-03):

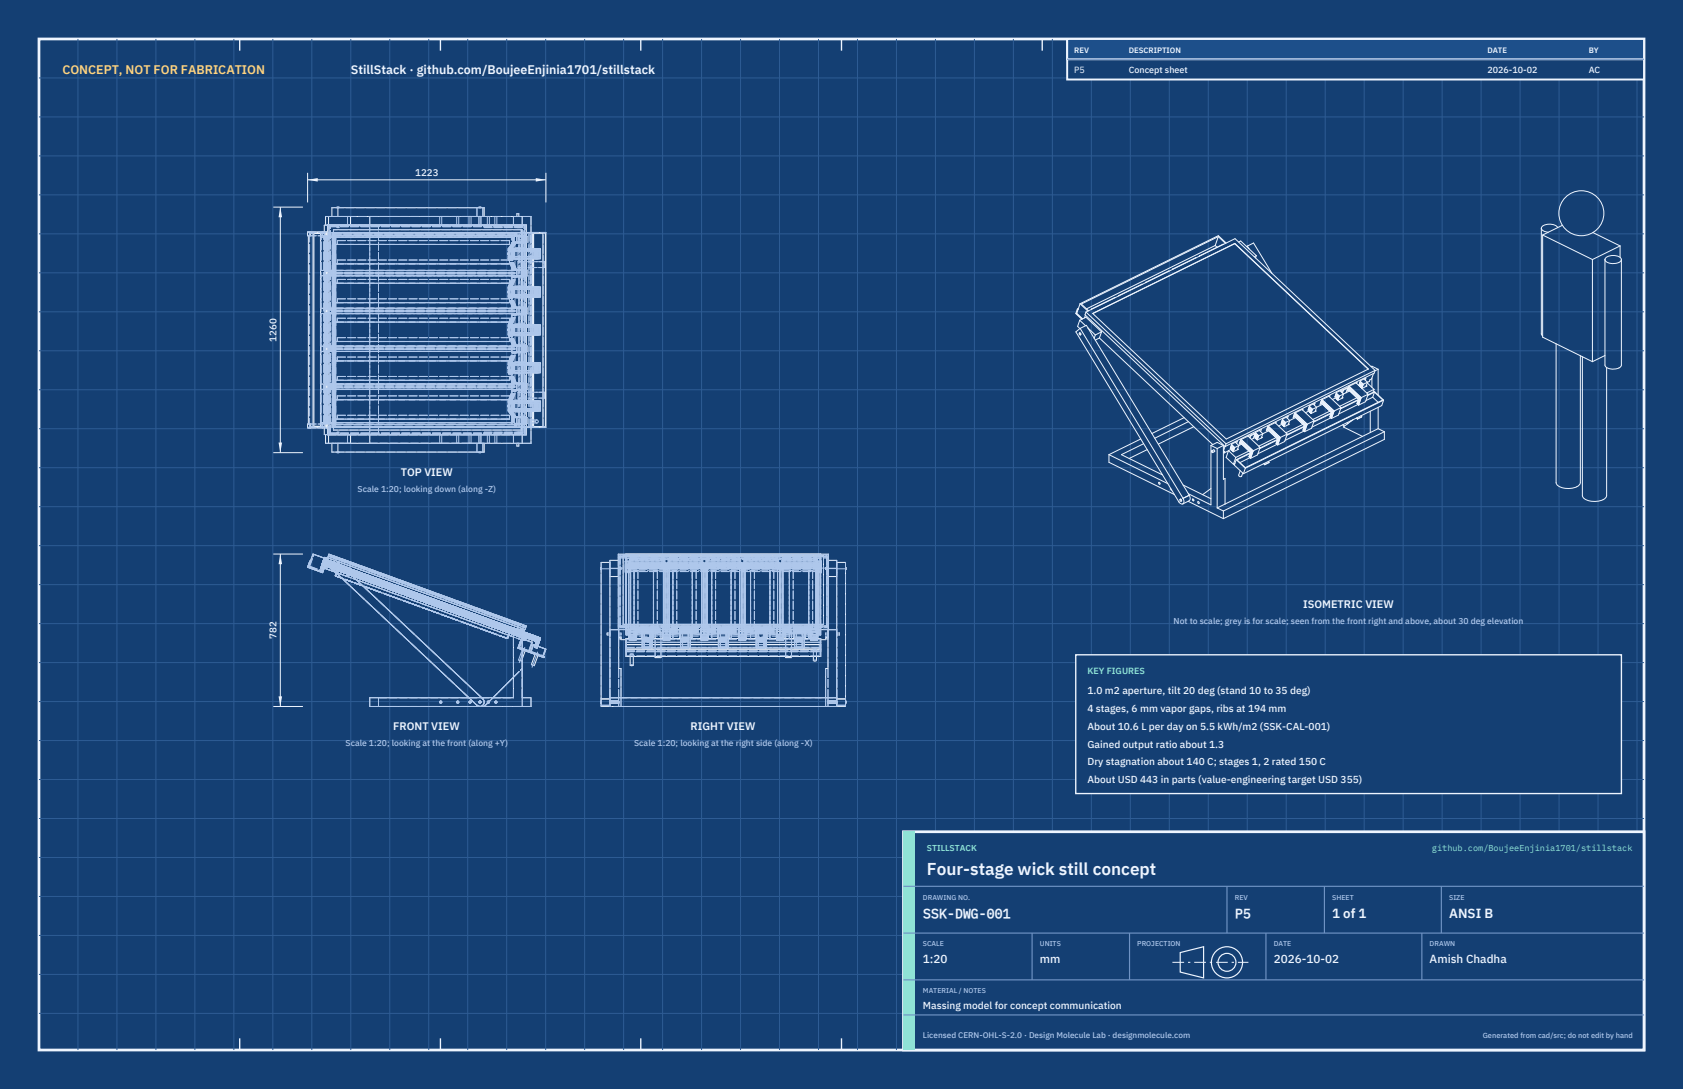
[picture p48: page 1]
CONCEPT, NOT FOR FABRICATION; StillStack · github.com/BoujeeEnjinia1701/stillstack; FRONT VIEW; TOP VIEW; RIGHT VIEW; ISOMETRIC VIEW; REV; DESCRIPTION; DATE; Concept sheet; STILLSTACK; github.com/BoujeeEnjinia1701/stillstack; DRAWING NO. SSK-DWG-001; REV P5; SHEET 1 of 1; SIZE ANSI B; SCALE 1:20; UNITS mm; PROJECTION; DRAWN Amish Chadha; Licensed CERN-OHL-S-2.0 · Design Molecule Lab · designmolecule.com; Generated from cad/src; do not edit by hand

Scale 1:20; looking down (along -Z)

Not to scale; grey is for scale; seen from the front right and above, about 30 deg elevation

KEY FIGURES
1.0 m2 aperture, tilt 20 deg (stand 10 to 35 deg)
4 stages, 6 mm vapor gaps, ribs at 194 mm
About 10.6 L per day on 5.5 kWh/m2 (SSK-CAL-001)
Gained output ratio about 1.3
Dry stagnation about 140 C; stages 1, 2 rated 150 C
About USD 443 in parts (value-engineering target USD 355)

Scale 1:20; looking at the front (along +Y)

Scale 1:20; looking at the right side (along -X)

Four-stage wick still concept

MATERIAL / NOTES
Massing model for concept communication

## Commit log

2026-09-24 Initial scaffold: standard open hardware layout, CERN-OHL-S v2 + MIT licenses
    Claude-Session: https://claude.ai/code/session_01XuhhSU4W6fYhgCfURbrkut
    [bom.csv]
2026-09-25 Adopt portfolio kit v1.3.0: session commands, scale figure, 3D viewer, flow diagrams
    Adds .claude/commands (/populate, /advance-trl3, /rein-in, /refresh-media)
    so every Claude Code session starts from the standard prompts, and extends
    concept media with a 1.75 m scale figure, an interactive glTF viewer and
    system or energy flow diagrams. TRL cap 3 unchanged.
    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
2026-09-25 Kit v1.3.1: renderer fixes from the TremorTrace pilot
    Context scale parts for small objects, cutaway exclusions, and text
    labels in flow diagrams.
    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
2026-09-25 Populate stillstack to a strong TRL 2 with concept media (batch 1)
    Problem, requirements and precis v0.2, massing model and concept media,
    indicative BOM, docs/REVIEW.md with decisions proposed and awaiting Amish.
    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
    [bom.csv]
2026-09-25 Advance stillstack to TRL 3 (batch 1)
    Decisions approved by Amish 2026-09-25 recorded in DDR-001. TRL 4 is on hold.
    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
    [bom.csv, side-rail.stl, stillstack-assembly.step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]
2026-09-26 Accept all recommendations (DDR-002), switch footer to designmolecule.com, add README write-up with new inspiration point
    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
    [bom.csv, stillstack-assembly.step]
2026-09-27 Product appearance model and photoreal renders
    Adds cad/src/product_model.py (appearance model for renders only, all main
    dimensions from model.py) and Blender renders in media/render-*.png,
    captioned with the project, repository and viewing direction. README leads
    with the product render; trl stays 3.
    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
2026-10-01 Image quality pass: legible exploded views, flow diagrams and drawing sheets
    Kit 1.6.1 image layout: the parts list sits in its own column, number bubbles sit on visible parts and never overlap, small parts get a leader, pictures are cropped to the subject, flow labels keep numbers with their units, and sheet captions and the revision table no longer overprint. Concept images, blueprint and general arrangement sheet regenerated; repo-specific labels moved clear of other text and lines.
2026-10-02 Kit 1.7.0: constructable design, illustrated build plan and design decisions register
    The design is now constructable: every part can be made and fits its neighbours, with each change recorded in a Design for construction decision record (made under Amish's 2026-09-30 instruction; ope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
    FlexHand also credits Dr. Geeti Chadha as a contribut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
    [bom.csv, stillstack-assembly.step, stillstack-assembly.stl]
2026-10-02 Record Amish's approval of the open-decision recommendations
    Amish approved the recommendation on every open decision in the design decisions register ("i approve your recommendations for all 555 open decisions.", 2026-10-02). Each decision is moved to Decisio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
2026-10-03 Carry approved follow-ups into the design and redo photoreal renders
    Amish approved the follow-up actions from the open-decision sign-off ("APPROVED CHANGES, COMPLETE THESE", 2026-10-02), the design-for-construction change tables in ten repos, the last wave's open dec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
    [bom.csv, stillstack-assembly.step, stillstack-assembly.stl]
2026-10-28 Kit 1.9.1 upgrade: pipeline documents and detailed CAD for every option
    Kit 1.9.1 installed (.kit, CLAUDE.md, .claude/commands). Kit 1.8 pipeline: STEM check with fixes under the 2026-10-23 standing instruction, concept options with the current design as option A, URS, PRS, generated RTM, REG, FEA, RSK with design FMEA, MKT, PLN and DDR; kit 1.9 D3 model of every option passing cad/fidelity.json; independent review recorded in the STEM check. Amish's 2026-10-25 decisions recorded where he approved a recommendation; all others proposed, awaiting Amish. Product renders and the options picture follow in a later commit where not yet included.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
2026-10-29 Add Cycles product renders and the concept options picture
    Blender Cycles renders of the kit 1.9.1 model, rendered on Amish's Mac and captioned; media/options.png from the D3 option models (this also clears the failing docs check, which needs the picture); cards and PDFs rebuilt. The options picture labels option A as the current design unless project.yaml records Amish's choice.
2026-10-29 Add the concept options picture rendered from the D3 option models
    media/options.png from Blender Cycles panels of every option, rendered on Amish's Mac; the label reads CURRENT DESIGN unless project.yaml records Amish's choice. Clears the docs check, which needs th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

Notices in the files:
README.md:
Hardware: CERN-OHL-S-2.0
